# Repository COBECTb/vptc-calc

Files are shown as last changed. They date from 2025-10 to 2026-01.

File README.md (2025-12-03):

# vptc-calc
Калькулятор ВПТК (Волновой редуктор с роликами)

## Запуск

```
docker build -t vptc-calculator .
```

```
docker run --rm -it \
  -v "$(pwd)/calc-vpts.py":/app/calc-vpts.py:ro \
  -v "$(pwd)/output":/app/output \
  vptc-calculator
```

## Описание

Калькулятор генерирует 3D-модель волнового редуктора с роликами (VPTC - Variable Pace Traction Coupling) с параметрами, задаваемыми пользователем. В папку output помещается файл vptc_roller.scad который необходимо открыть в программе OpenSCAD.

## Генерируемые детали

Программа генерирует следующие основные детали:

### 1. Жёсткое колесо (Corpus редуктора) - `rigid_gear()`
- Внешний корпус редуктора с профильными впадинами
- Имеет крепёжные отверстия группы A (для крепления крышки)
- Имеет крепёжные отверстия группы B (для кожуха мотора)
- Посадочное место под подшипник 6803ZZ в корпусе
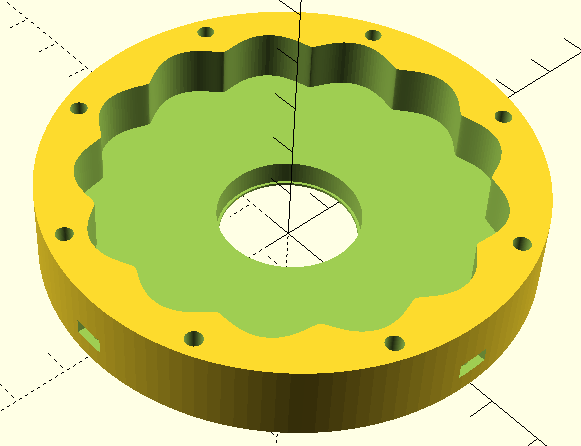
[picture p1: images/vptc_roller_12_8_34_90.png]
vptc_roller_12_8_34_90


### 2. Корпус с боковым креплением - `rigid_gear_with_bracing()`
- Усиленная версия жёсткого колеса с дополнительными элементами бокового крепления

### 3. Сепаратор - `separator()`
- Держатель роликов с фланцем под основной подшипник
- Имеет посадочное место под подшипник 688ZZ (8x16x5) на конце
- Содержит отверстия для роликов
- Имеет крепёжные отверстия для нагрузки

### 4. Ролики - `rollers()`
- Цилиндрические ролики, размещаемые в сепараторе
- Количество определяется передаточным числом

### 5. Эксцентрик - `eccentric()`
- Эксцентриковая деталь, обеспечивающая волновую передачу
- Имеет посадочное место под подшипник 6803ZZ

### 6. Вал эксцентрика - `eccentric_shaft()`
- Основной вал с эксцентриковой ступенью
- Содержит посадочные места под подшипники
- Имеет шип для крепления сепаратора

### 7. Крышка редуктора - `cap()`
- Крышка корпуса с отверстиями для крепления
- Потайные отверстия под винты М3

### 8. Крышка с боковым креплением - `cap_with_bracing()`
- Усиленная версия крышки с элементами бокового крепления

### 9. Защитный кожух мотора - `motor_cover()`
- Защитный кожух для двигателя с креплением
- Имеет отверстия для крепления двигателя
- Центральное отверстие под магнит энкодера

### 10. Соединитель редукторов - `reducer_connector()`
- Элемент для соединения нескольких редукторов

### 11. Зажим соединителей - `connector_clamp()`
- Крепежный элемент для соединителей

## Управление сборкой

Внизу, в секции "Сборка", перечисляются детали, можно их создание раскомментировать и подвигать функцией translate:

```
// === Сборка ===
rigid_gear_with_bracing();  // Корпус с боковым креплением
translate([0, 0, h_reducer+1]) cap_with_bracing();  // Крышка с боковым креплением
translate([0, 0, 0.5]) eccentric_shaft();
translate([0, 0, 14]) rotate([180,0,0]) eccentric();
translate([0, 0, ecc_shaft_h1 + ecc_spacer_h-1]) separator();
translate([0, 0, -mc_total_height-1]) motor_cover(); // кожух снизу
```

## Параметры моделирования

Параметр $fn отвечает за разрешение геометрии модели:
```
// ВПТК редуктор с роликами

$fn = 60;  // Рекомендуемое значение для 3D печати
```

В редакторе OpenSCAD есть кнопки рендеринга и экспорт в STL.

## Параметры, запрашиваемые при запуске

- **Количество точек построения профиля жесткого колеса** (по умолчанию: 600) - влияет на точность профиля
- **Передаточное число** (по умолчанию: 19) - основной параметр передачи
- **Диаметр роликов (мм)** (по умолчанию: 4.0) - диаметр роликов сепаратора
- **Высота роликов (мм)** (по умолчанию: 5.0) - высота роликов сепаратора
- **Внешний радиус впадин жесткого колеса (мм)** (по умолчанию: 29.0) - радиус профиля жесткого колеса
- **Внешний диаметр редуктора (мм)** (по умолчанию: 70.0) - общий диаметр корпуса

## Список деталей и крепежа

Программа автоматически выводит список всех необходимых деталей и крепежа, включая:
- Подшипники: 6803ZZ (17×26×5 мм), 688ZZ (8×16×5 мм), и подшипник для сепаратора (6808-2RS или 6810-2RS)
- Винты: M3×10 мм и M3×15 мм
- Гайки: M3

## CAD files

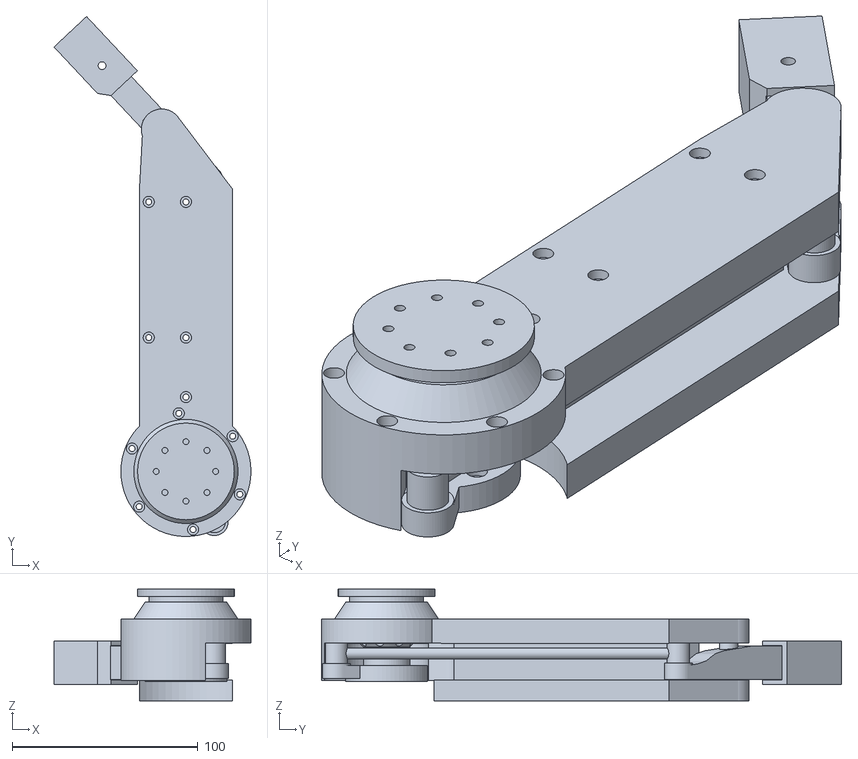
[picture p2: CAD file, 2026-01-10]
output/vptc_roller_19_4_5_70_leg_left_front.stl
106.0 x 279.8 x 60.1

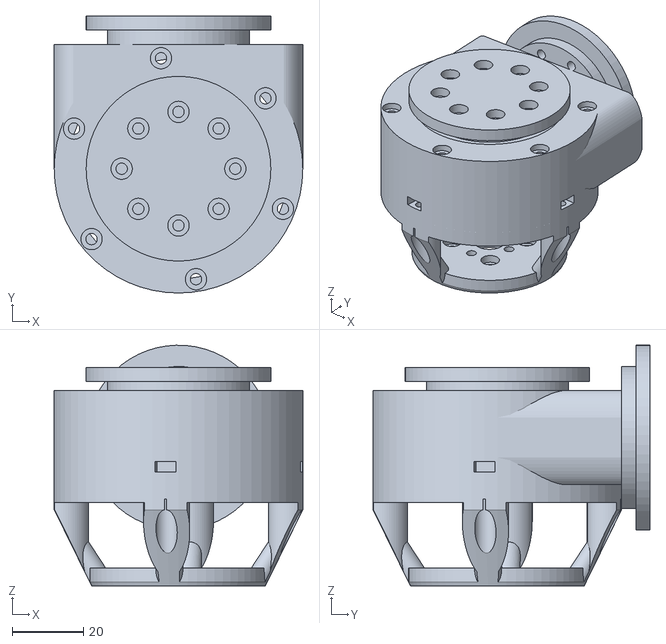
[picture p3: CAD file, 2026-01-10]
output/vptc_roller_19_4_5_70_reducer_with_bracing_and_connector.stl
70.0 x 78.0 x 67.7

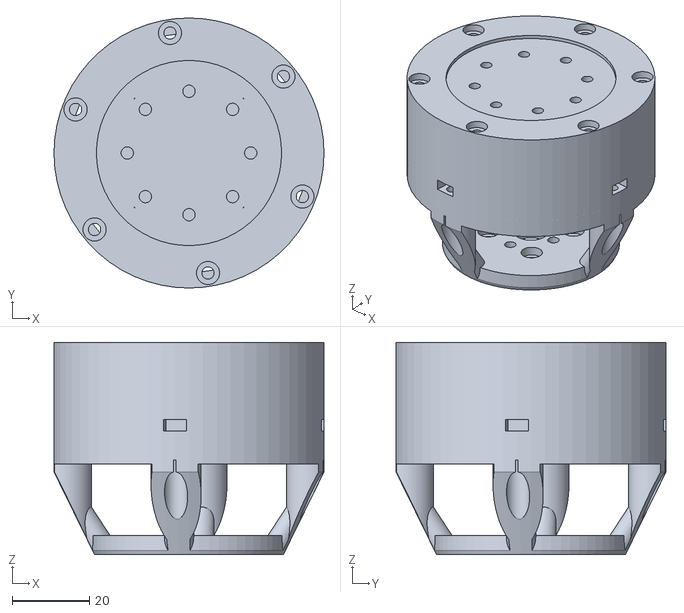
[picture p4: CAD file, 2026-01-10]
output/vptc_roller_19_4_5_70_reducer.stl
70.0 x 70.0 x 55.0

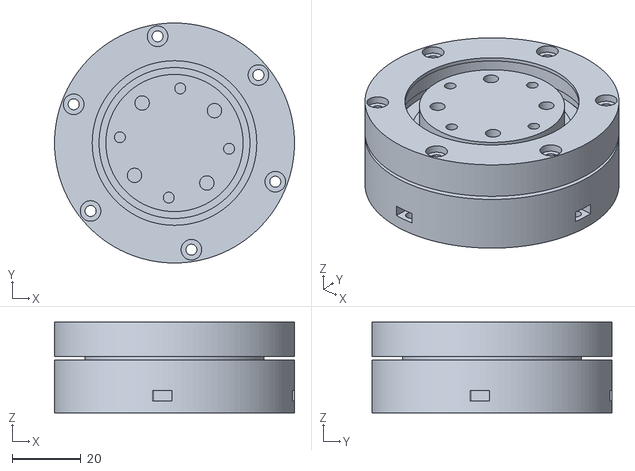
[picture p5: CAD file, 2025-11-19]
output/vptc_roller_19_4_5_70.stl
70.0 x 70.0 x 26.5

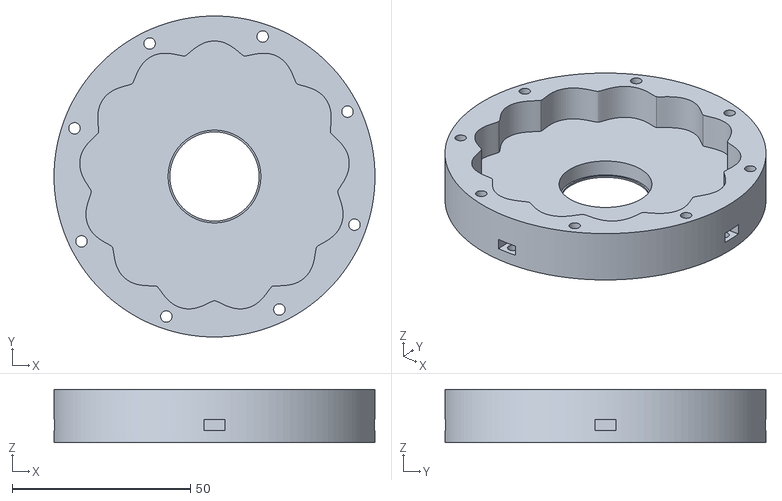
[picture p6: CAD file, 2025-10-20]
output/vptc_roller_12_8_34_90.stl
90.0 x 90.0 x 15.0

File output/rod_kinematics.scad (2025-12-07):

// ========== ФУНКЦИИ РАСЧЕТА (ваши) ==========
function calculate_rigid_linkage(
    angle1, rod_length, radius1, radius2, center1, center2
) = 
let(
    a1 = angle1,
    P1 = [center1.x + radius1 * cos(a1), center1.y + radius1 * sin(a1), center1.z],
    dx = center2.x - P1.x,
    dy = center2.y - P1.y,
    d = sqrt(dx*dx + dy*dy),
    min_length = abs(d - radius2),
    max_length = d + radius2,
    solution_exists = (rod_length >= min_length) && (rod_length <= max_length),
    P2 = solution_exists ? 
        let(
            cos_phi = (d*d + radius2*radius2 - rod_length*rod_length) / (2 * d * radius2),
            theta = atan2(P1.y - center2.y, P1.x - center2.x),
            alpha = acos(cos_phi),
            angle2 = theta + alpha,
            point2 = [center2.x + radius2 * cos(angle2), center2.y + radius2 * sin(angle2), center2.z]
        )
        point2
        : [0, 0, 0],
    angle2_result = solution_exists ? atan2(P2.y - center2.y, P2.x - center2.x) : 0
)
[
    ["point1", P1], ["point2", P2], ["angle1", angle1], ["angle2", angle2_result],
    ["solution_exists", solution_exists], ["distance", rod_length],
    ["min_possible", min_length], ["max_possible", max_length]
];

function get_value(data, key) = 
    let(idx = search([key], data, num_returns_per_match=1)[0])
    data[idx][1];

// ========== МОДУЛИ ДЛЯ ОТРИСОВКИ ==========

// Модуль для соединения двух точек цилиндром
module connect_points(p1, p2, diameter = 3) {
    hole_diameter= 3;
    plate_thickness = 2;       // Толщина пластины
    plate_diameter = hole_diameter * 3; // Диаметр круглой пластины

    vec = p2 - p1;
    length = norm(vec);
    
    // Угол в плоскости XY
    angle = atan2(vec.y, vec.x);
    
    translate(p1)
    rotate([0, 90, angle])  // Вот это правильный порядок!
        cylinder(h = length, d = diameter, center = false);
    translate(p1)
    difference() {
                cylinder( h = plate_thickness, d = plate_diameter, center = true );
                // Отверстие для оси шарнира (перпендикулярно тяге)
                cylinder( h = plate_thickness * 2, d = hole_diameter, center = true );
            };
    translate(p2)
    difference() {
                cylinder( h = plate_thickness+10, d = plate_diameter, center = true );
                // Отверстие для оси шарнира (перпендикулярно тяге)
                cylinder( h = plate_thickness * 2, d = hole_diameter, center = true );
            };
}

// Модуль для отрисовки качалки (рычага)
module draw_arm(center, radius, angle, width = 6, thickness = 4, color = "red") {
    color(color) {
        // Центральная ступица
        translate(center)
            cylinder(h = thickness + 2, d = 10, center = true);
        
        // Рычаг
        translate(center)
        rotate([0, 0, angle]) {
            // Основание рычага
            cylinder(h = thickness, d = width, center = true);
            
            // Длина рычага до точки крепления
            translate([radius, 0, 0])
                cylinder(h = thickness, d = width, center = true);
            
            // Соединяющая часть
            hull() {
                cylinder(h = thickness, d = width, center = true);
                translate([radius, 0, 0])
                    cylinder(h = thickness, d = width, center = true);
            }
            
            // Точка крепления (усиленная)
            translate([radius, 0, 0])
                cylinder(h = thickness + 4, d = 8, center = true);
        }
    }
}

// Модуль для отрисовки основания
module draw_base(position, size = [40, 40, 5], color = "gray") {
    color(color, 0.5)
    translate(position - [0, 0, size.z/2])
        cube(size, center = true);
}

// Модуль для отрисовки всей системы
module draw_linkage_system(
    servo_angle, rod_length, radius1, radius2, center1, center2,
    show_trajectory = true
) {
    // Выполняем расчет
    result = calculate_rigid_linkage(
        servo_angle, rod_length, radius1, radius2, center1, center2
    );
    
    // Извлекаем результаты
    point1 = get_value(result, "point1");
    point2 = get_value(result, "point2");
    angle2 = get_value(result, "angle2");
    solution_exists = get_value(result, "solution_exists");
    
    // Если решение существует - рисуем механизм
    if (solution_exists) {
        // 1. ОСНОВАНИЯ
        draw_base(center1, [50, 50, 8], "lightgray");
        draw_base(center2, [50, 50, 8], "lightgray");
        
        // 2. ПЕРВАЯ КАЧАЛКА (сервопривод)
        draw_arm(center1, radius1, servo_angle, 6, 4, "red");
        
        // 3. ВТОРАЯ КАЧАЛКА (колено)
        draw_arm(center2, radius2, angle2, 6, 4, "blue");
        
        // 4. ТЯГА (стержень)
        color("silver") {
            connect_points(point1, point2, 5);
            
            // Шарнирные шарики на концах
            translate(point1) sphere(d = 10);
            translate(point2) sphere(d = 10);
        }
        
        // 5. ЦЕНТРЫ ВРАЩЕНИЯ (оси)
        color("black") {
            // Ось сервопривода
            translate(center1)
                cylinder(h = 15, d = 4, center = true);
            
            // Ось колена
            translate(center2)
                cylinder(h = 15, d = 4, center = true);
        }
        
        // 6. ТРАЕКТОРИИ ДВИЖЕНИЯ (полупрозрачные)
        if (show_trajectory) {
            // Траектория точки P1
            color("red", 0.2)
            translate(center1)
                cylinder(h = 0.5, r = radius1, center = true);
            
            // Траектория точки P2 для всех углов
            color("blue", 0.2) 
            for(ang = [0:10:360]) {
                test_result = calculate_rigid_linkage(
                    ang, rod_length, radius1, radius2, center1, center2
                );
                if (get_value(test_result, "solution_exists")) {
                    test_p2 = get_value(test_result, "point2");
                    translate(test_p2)
                        sphere(r = 1);
                }
            }
        }
        
        // 7. ИНФОРМАЦИОННАЯ ПАНЕЛЬ
        color("black")
        translate([0, -50, 20])
        linear_extrude(1) {
            text(str("Сервопривод: ", round(servo_angle), "°"), 
                 size = 5, halign = "center");
            
            translate([0, -7, 0])
            text(str("Колено: ", round(angle2), "°"), 
                 size = 5, halign = "center");
            
            translate([0, -14, 0])
            text(str("Длина тяги: ", rod_length, "мм"), 
                 size = 5, halign = "center");
        }
        
    } else {
        // Если решения нет - показываем сообщение об ошибке
        color("red")
        translate([0, 0, 30])
        linear_extrude(2)
            text("НЕТ РЕШЕНИЯ!", size = 10, halign = "center");
    }
}

// ========== ПАРАМЕТРЫ И ВЫЗОВ ==========

// Параметры механизма
rod_length = 90;
radius1 = 20;
radius2 = 25;
center1 = [0, 0, 0];
center2 = [80, 30, 0];

// Для анимации используем $t (от 0 до 1)
servo_angle = $t * 270 - 135;  // От -135° до +135°

// Отрисовываем систему
draw_linkage_system(
    servo_angle = servo_angle,
    rod_length = rod_length,
    radius1 = radius1,
    radius2 = radius2,
    center1 = center1,
    center2 = center2,
    show_trajectory = true
);

// ========== ДОПОЛНИТЕЛЬНАЯ ВИЗУАЛИЗАЦИЯ ==========

// Ради удобства - рисуем сетку координат
%color("gray", 0.2) {
    // Оси координат
    cylinder(h = 100, r = 0.5, center = true); // Z
    rotate([90, 0, 0]) cylinder(h = 100, r = 0.5, center = true); // Y
    rotate([0, 90, 0]) cylinder(h = 100, r = 0.5, center = true); // X
    
    // Подписи осей
    translate([105, 0, 0]) text("X", size = 5);
    translate([0, 105, 0]) text("Y", size = 5);
    translate([0, 0, 105]) text("Z", size = 5);
}

// ========== ПРОВЕРОЧНЫЙ РАСЧЕТ ==========

// Выводим значения в консоль для текущего угла
echo(" ");
echo("=== РАСЧЕТ ДЛЯ УГЛА ", servo_angle, "° ===");

result = calculate_rigid_linkage(
    servo_angle, rod_length, radius1, radius2, center1, center2
);

point1 = get_value(result, "point1");
point2 = get_value(result, "point2");
angle2 = get_value(result, "angle2");
solution_exists = get_value(result, "solution_exists");
min_possible = get_value(result, "min_possible");
max_possible = get_value(result, "max_possible");

echo("Точка 1: ", point1);
echo("Точка 2: ", point2);
echo("Угол колена: ", angle2, "° (", angle2 * 180 / 3.14159, "°)");
echo("Длина тяги (расчетная): ", norm(point2 - point1), "мм");
echo("Диапазон возможных длин: от ", min_possible, " до ", max_possible, "мм");
echo("Решение существует: ", solution_exists);

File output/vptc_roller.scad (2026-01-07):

// ВПТК редуктор с роликами (для 3D-печати)
$fn = 60;
// Параметры
d_roller = 4.000;
h_roller = 5.000;
separator_h = 9.000;
eccentric_h = 7.000;
Rsep_m = 25.200;
Rsep_out = 26.080;
Rsep_in = 24.320;
D_out = 70.000;
h_reducer = 15.500;
bearing_inner = 40.0;
// Высота профильного выреза
h_cut = h_roller + 5;
cap_thickness = 11.0;
eccentricity = 0.800;
// --- Параметры вала эксцентрика ---
ecc_shaft_h1 = 5.000;   // основание под 6803ZZ
ecc_spacer_h = 2.500;   // проставка
ecc_shaft_h2 = 6.000;   // эксцентриковая ступень
ecc_pin_h = 6.000;      // шип под 688ZZ
// --- Параметры кожуха мотора ---
mc_motor_plate_d = 50.0;
mc_base_thickness = 4.0;
mc_encoder_hole_d = 10.0;
mc_motor_hole_1 = 16.0;
mc_motor_hole_2 = 19.0;
mc_nut_pad_radius = 24.0;
mc_nut_pad_d = 6.0;
mc_nut_pad_h = 3.0;
mc_total_height = 27.5;
mc_ring_width = 4.0;
mc_ring_height = 5.0;
mc_countersink_d = 6.0;
mc_countersink_h = 2.0;
// --- Параметры бокового крепления ---
bracing_offset_y = 29.0;  // смещение по Y
bracing_offset_z = 17.5;  // смещение по Z
bracing_offset_x = 2.2;  // смещение по X

// === Группа B: отверстия под кожух мотора нужны в двух функциях===
motor_angles = [174.0, 264.0, 354.0, 84.0];
motor_radius = 32.000;

// Расстояния между отверстиями в боковом креплении
side_short = 12.246;
side_long = 29.564;

zazor=0; //отступ для раздельной печати деталей, чтобы при импорте stl можно было разделить на отделтные детали
// === Вспомогательные модули для бокового крепления ===
module oval_cone(height, bottom_width, bottom_depth, top_width, top_depth, center = false) {
    hull() {
        // Нижнее основание
        translate([0, 0, center ? -height/2 : 0])
        scale([bottom_width/2, bottom_depth/2, 1])
        cylinder(h = 0.1, r = 1, center = true, $fn = 64);
        
        // Верхнее основание
        translate([0, 0, center ? height/2 : height])
        scale([top_width/2, top_depth/2, 1])
        cylinder(h = 0.1, r = 1, center = true, $fn = 64);
    }
}

module oval_cone_diff_half(height, bottom_width, bottom_depth, top_width, top_depth, center = false) {
    difference() { 
        cube([height, height, height], center = center);
        // Вычитаем овальный конус
        oval_cone(height, bottom_width, bottom_depth, top_width, top_depth, center = center);
        translate([0, height/4, 0]) cube([height, height/2, height], center = center);
    }
}

// === Корпус (жёсткое колесо) ===
module rigid_gear() {
    difference() {
        cylinder(h = h_reducer, r = D_out / 2, center = false);
        translate([0, 0, h_reducer - h_cut])
            linear_extrude(height = h_cut, center = false)
                polygon(points = [
                [0.00000, 28.00000], [0.55458, 27.96049], [1.08358, 27.84861], [1.56964, 27.68091], [2.00602, 27.47706],
        [2.39362, 27.25494], [2.73674, 27.02909], [3.03997, 26.81126], [3.30657, 26.61130], [3.53787, 26.43755],
        [3.73313, 26.29670], [3.88995, 26.19284], [4.00545, 26.12612], [4.07887, 26.09136], [4.11549, 26.07829],
        [4.12987, 26.07497], [4.14457, 26.07368], [4.18344, 26.07480], [4.26401, 26.08517], [4.39447, 26.11293],
        [4.57571, 26.16324], [4.80494, 26.23687], [5.07860, 26.33064], [5.39395, 26.43843], [5.74965, 26.55189],
        [6.14577, 26.66065], [6.58304, 26.75213], [7.06105, 26.81115], [7.57515, 26.82045], [8.11283, 26.76338],
        [8.65248, 26.62958], [9.16770, 26.42064], [9.63624, 26.15076], [10.04669, 25.84106], [10.39872, 25.51235],
        [10.69871, 25.18132], [10.95525, 24.86049], [11.17632, 24.55962], [11.36808, 24.28706], [11.53437, 24.05034],
        [11.67654, 23.85604], [11.79359, 23.70881], [11.88282, 23.60967], [11.94190, 23.55392], [11.97270, 23.53017],
        [11.98535, 23.52257], [11.99893, 23.51680], [12.03624, 23.50585], [12.11608, 23.49082], [12.24873, 23.47691],
        [12.43665, 23.46875], [12.67741, 23.46794], [12.96665, 23.47255], [13.29987, 23.47762], [13.67322, 23.47561],
        [14.08357, 23.45664], [14.52771, 23.40852], [15.00056, 23.31694], [15.49237, 23.16691], [15.98610, 22.94649],
        [16.45799, 22.65248], [16.88343, 22.29454], [17.24564, 21.89309], [17.54030, 21.47171], [17.77352, 21.05030],
        [17.95653, 20.64277], [18.10137, 20.25837], [18.21865, 19.90391], [18.31680, 19.58544], [18.40180, 19.30892],
        [18.47697, 19.08020], [18.54280, 18.90400], [18.59702, 18.78213], [18.63599, 18.71086], [18.65794, 18.67875],
        [18.66762, 18.66762], [18.67875, 18.65794], [18.71086, 18.63599], [18.78213, 18.59702], [18.90400, 18.54280],
        [19.08020, 18.47697], [19.30892, 18.40180], [19.58544, 18.31680], [19.90391, 18.21865], [20.25837, 18.10137],
        [20.64277, 17.95653], [21.05030, 17.77352], [21.47171, 17.54030], [21.89309, 17.24564], [22.29454, 16.88343],
        [22.65248, 16.45799], [22.94649, 15.98610], [23.16691, 15.49237], [23.31694, 15.00056], [23.40852, 14.52771],
        [23.45664, 14.08357], [23.47561, 13.67322], [23.47762, 13.29987], [23.47255, 12.96665], [23.46794, 12.67741],
        [23.46875, 12.43665], [23.47691, 12.24873], [23.49082, 12.11608], [23.50585, 12.03624], [23.51680, 11.99893],
        [23.52257, 11.98535], [23.53017, 11.97270], [23.55392, 11.94190], [23.60967, 11.88282], [23.70881, 11.79359],
        [23.85604, 11.67654], [24.05034, 11.53437], [24.28706, 11.36808], [24.55962, 11.17632], [24.86049, 10.95525],
        [25.18132, 10.69871], [25.51235, 10.39872], [25.84106, 10.04669], [26.15076, 9.63624], [26.42064, 9.16770],
        [26.62958, 8.65248], [26.76338, 8.11283], [26.82045, 7.57515], [26.81115, 7.06105], [26.75213, 6.58304],
        [26.66065, 6.14577], [26.55189, 5.74965], [26.43843, 5.39395], [26.33064, 5.07860], [26.23687, 4.80494],
        [26.16324, 4.57571], [26.11293, 4.39447], [26.08517, 4.26401], [26.07480, 4.18344], [26.07368, 4.14457],
        [26.07497, 4.12987], [26.07829, 4.11549], [26.09136, 4.07887], [26.12612, 4.00545], [26.19284, 3.88995],
        [26.29670, 3.73313], [26.43755, 3.53787], [26.61130, 3.30657], [26.81126, 3.03997], [27.02909, 2.73674],
        [27.25494, 2.39362], [27.47706, 2.00602], [27.68091, 1.56964], [27.84861, 1.08358], [27.96049, 0.55458],
        [28.00000, 0.00000], [27.96049, -0.55458], [27.84861, -1.08358], [27.68091, -1.56964], [27.47706, -2.00602],
        [27.25494, -2.39362], [27.02909, -2.73674], [26.81126, -3.03997], [26.61130, -3.30657], [26.43755, -3.53787],
        [26.29670, -3.73313], [26.19284, -3.88995], [26.12612, -4.00545], [26.09136, -4.07887], [26.07829, -4.11549],
        [26.07497, -4.12987], [26.07368, -4.14457], [26.07480, -4.18344], [26.08517, -4.26401], [26.11293, -4.39447],
        [26.16324, -4.57571], [26.23687, -4.80494], [26.33064, -5.07860], [26.43843, -5.39395], [26.55189, -5.74965],
        [26.66065, -6.14577], [26.75213, -6.58304], [26.81115, -7.06105], [26.82045, -7.57515], [26.76338, -8.11283],
        [26.62958, -8.65248], [26.42064, -9.16770], [26.15076, -9.63624], [25.84106, -10.04669], [25.51235, -10.39872],
        [25.18132, -10.69871], [24.86049, -10.95525], [24.55962, -11.17632], [24.28706, -11.36808], [24.05034, -11.53437],
        [23.85604, -11.67654], [23.70881, -11.79359], [23.60967, -11.88282], [23.55392, -11.94190], [23.53017, -11.97270],
        [23.52257, -11.98535], [23.51680, -11.99893], [23.50585, -12.03624], [23.49082, -12.11608], [23.47691, -12.24873],
        [23.46875, -12.43665], [23.46794, -12.67741], [23.47255, -12.96665], [23.47762, -13.29987], [23.47561, -13.67322],
        [23.45664, -14.08357], [23.40852, -14.52771], [23.31694, -15.00056], [23.16691, -15.49237], [22.94649, -15.98610],
        [22.65248, -16.45799], [22.29454, -16.88343], [21.89309, -17.24564], [21.47171, -17.54030], [21.05030, -17.77352],
        [20.64277, -17.95653], [20.25837, -18.10137], [19.90391, -18.21865], [19.58544, -18.31680], [19.30892, -18.40180],
        [19.08020, -18.47697], [18.90400, -18.54280], [18.78213, -18.59702], [18.71086, -18.63599], [18.67875, -18.65794],
        [18.66762, -18.66762], [18.65794, -18.67875], [18.63599, -18.71086], [18.59702, -18.78213], [18.54280, -18.90400],
        [18.47697, -19.08020], [18.40180, -19.30892], [18.31680, -19.58544], [18.21865, -19.90391], [18.10137, -20.25837],
        [17.95653, -20.64277], [17.77352, -21.05030], [17.54030, -21.47171], [17.24564, -21.89309], [16.88343, -22.29454],
        [16.45799, -22.65248], [15.98610, -22.94649], [15.49237, -23.16691], [15.00056, -23.31694], [14.52771, -23.40852],
        [14.08357, -23.45664], [13.67322, -23.47561], [13.29987, -23.47762], [12.96665, -23.47255], [12.67741, -23.46794],
        [12.43665, -23.46875], [12.24873, -23.47691], [12.11608, -23.49082], [12.03624, -23.50585], [11.99893, -23.51680],
        [11.98535, -23.52257], [11.97270, -23.53017], [11.94190, -23.55392], [11.88282, -23.60967], [11.79359, -23.70881],
        [11.67654, -23.85604], [11.53437, -24.05034], [11.36808, -24.28706], [11.17632, -24.55962], [10.95525, -24.86049],
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

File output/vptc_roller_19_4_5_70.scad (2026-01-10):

// ВПТК редуктор с роликами (для 3D-печати)
$fn = 60;
// Параметры
d_roller = 4.000;
h_roller = 5.000;
separator_h = 9.000;
eccentric_h = 7.000;
Rsep_m = 25.200;
Rsep_out = 26.080;
Rsep_in = 24.320;
D_out = 70.000;
h_reducer = 15.500;
bearing_inner = 40.0;
// Высота профильного выреза
h_cut = h_roller + 5;
cap_thickness = 11.0;
eccentricity = 0.800;
// --- Параметры вала эксцентрика ---
ecc_shaft_h1 = 5.000;   // основание под 6803ZZ
ecc_spacer_h = 2.500;   // проставка
ecc_shaft_h2 = 6.000;   // эксцентриковая ступень
ecc_pin_h = 6.000;      // шип под 688ZZ
// --- Параметры кожуха мотора ---
mc_motor_plate_d = 50.0;
mc_base_thickness = 4.0;
mc_encoder_hole_d = 10.0;
mc_motor_hole_1 = 16.0;
mc_motor_hole_2 = 19.0;
mc_nut_pad_radius = 24.0;
mc_nut_pad_d = 6.0;
mc_nut_pad_h = 3.0;
mc_total_height = 27.5;
mc_ring_width = 4.0;
mc_ring_height = 5.0;
mc_countersink_d = 6.0;
mc_countersink_h = 2.0;
// --- Параметры бокового крепления ---
bracing_offset_y = 29.0;  // смещение по Y
bracing_offset_z = 17.5;  // смещение по Z
bracing_offset_x = 2.2;  // смещение по X

// === Группа B: отверстия под кожух мотора нужны в двух функциях===
motor_angles = [174.0, 264.0, 354.0, 84.0];
motor_radius = 32.000;

// Расстояния между отверстиями в боковом креплении
side_short = 12.246;
side_long = 29.564;

zazor=0; //отступ для раздельной печати деталей, чтобы при импорте stl можно было разделить на отделтные детали
// === Вспомогательные модули для бокового крепления ===
module oval_cone(height, bottom_width, bottom_depth, top_width, top_depth, center = false) {
    hull() {
        // Нижнее основание
        translate([0, 0, center ? -height/2 : 0])
        scale([bottom_width/2, bottom_depth/2, 1])
        cylinder(h = 0.1, r = 1, center = true, $fn = 64);
        
        // Верхнее основание
        translate([0, 0, center ? height/2 : height])
        scale([top_width/2, top_depth/2, 1])
        cylinder(h = 0.1, r = 1, center = true, $fn = 64);
    }
}

module oval_cone_diff_half(height, bottom_width, bottom_depth, top_width, top_depth, center = false) {
    difference() { 
        cube([height, height, height], center = center);
        // Вычитаем овальный конус
        oval_cone(height, bottom_width, bottom_depth, top_width, top_depth, center = center);
        translate([0, height/4, 0]) cube([height, height/2, height], center = center);
    }
}

// === Корпус (жёсткое колесо) ===
module rigid_gear() {
    difference() {
        cylinder(h = h_reducer, r = D_out / 2, center = false);
        translate([0, 0, h_reducer - h_cut])
            linear_extrude(height = h_cut, center = false)
                polygon(points = [
                [0.00000, 28.00000], [0.55458, 27.96049], [1.08358, 27.84861], [1.56964, 27.68091], [2.00602, 27.47706],
        [2.39362, 27.25494], [2.73674, 27.02909], [3.03997, 26.81126], [3.30657, 26.61130], [3.53787, 26.43755],
        [3.73313, 26.29670], [3.88995, 26.19284], [4.00545, 26.12612], [4.07887, 26.09136], [4.11549, 26.07829],
        [4.12987, 26.07497], [4.14457, 26.07368], [4.18344, 26.07480], [4.26401, 26.08517], [4.39447, 26.11293],
        [4.57571, 26.16324], [4.80494, 26.23687], [5.07860, 26.33064], [5.39395, 26.43843], [5.74965, 26.55189],
        [6.14577, 26.66065], [6.58304, 26.75213], [7.06105, 26.81115], [7.57515, 26.82045], [8.11283, 26.76338],
        [8.65248, 26.62958], [9.16770, 26.42064], [9.63624, 26.15076], [10.04669, 25.84106], [10.39872, 25.51235],
        [10.69871, 25.18132], [10.95525, 24.86049], [11.17632, 24.55962], [11.36808, 24.28706], [11.53437, 24.05034],
        [11.67654, 23.85604], [11.79359, 23.70881], [11.88282, 23.60967], [11.94190, 23.55392], [11.97270, 23.53017],
        [11.98535, 23.52257], [11.99893, 23.51680], [12.03624, 23.50585], [12.11608, 23.49082], [12.24873, 23.47691],
        [12.43665, 23.46875], [12.67741, 23.46794], [12.96665, 23.47255], [13.29987, 23.47762], [13.67322, 23.47561],
        [14.08357, 23.45664], [14.52771, 23.40852], [15.00056, 23.31694], [15.49237, 23.16691], [15.98610, 22.94649],
        [16.45799, 22.65248], [16.88343, 22.29454], [17.24564, 21.89309], [17.54030, 21.47171], [17.77352, 21.05030],
        [17.95653, 20.64277], [18.10137, 20.25837], [18.21865, 19.90391], [18.31680, 19.58544], [18.40180, 19.30892],
        [18.47697, 19.08020], [18.54280, 18.90400], [18.59702, 18.78213], [18.63599, 18.71086], [18.65794, 18.67875],
        [18.66762, 18.66762], [18.67875, 18.65794], [18.71086, 18.63599], [18.78213, 18.59702], [18.90400, 18.54280],
        [19.08020, 18.47697], [19.30892, 18.40180], [19.58544, 18.31680], [19.90391, 18.21865], [20.25837, 18.10137],
        [20.64277, 17.95653], [21.05030, 17.77352], [21.47171, 17.54030], [21.89309, 17.24564], [22.29454, 16.88343],
        [22.65248, 16.45799], [22.94649, 15.98610], [23.16691, 15.49237], [23.31694, 15.00056], [23.40852, 14.52771],
        [23.45664, 14.08357], [23.47561, 13.67322], [23.47762, 13.29987], [23.47255, 12.96665], [23.46794, 12.67741],
        [23.46875, 12.43665], [23.47691, 12.24873], [23.49082, 12.11608], [23.50585, 12.03624], [23.51680, 11.99893],
        [23.52257, 11.98535], [23.53017, 11.97270], [23.55392, 11.94190], [23.60967, 11.88282], [23.70881, 11.79359],
        [23.85604, 11.67654], [24.05034, 11.53437], [24.28706, 11.36808], [24.55962, 11.17632], [24.86049, 10.95525],
        [25.18132, 10.69871], [25.51235, 10.39872], [25.84106, 10.04669], [26.15076, 9.63624], [26.42064, 9.16770],
        [26.62958, 8.65248], [26.76338, 8.11283], [26.82045, 7.57515], [26.81115, 7.06105], [26.75213, 6.58304],
        [26.66065, 6.14577], [26.55189, 5.74965], [26.43843, 5.39395], [26.33064, 5.07860], [26.23687, 4.80494],
        [26.16324, 4.57571], [26.11293, 4.39447], [26.08517, 4.26401], [26.07480, 4.18344], [26.07368, 4.14457],
        [26.07497, 4.12987], [26.07829, 4.11549], [26.09136, 4.07887], [26.12612, 4.00545], [26.19284, 3.88995],
        [26.29670, 3.73313], [26.43755, 3.53787], [26.61130, 3.30657], [26.81126, 3.03997], [27.02909, 2.73674],
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

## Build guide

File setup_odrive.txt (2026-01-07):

odrv0.axis0.error=0
odrv0.axis0.requested_state = AXIS_STATE_FULL_CALIBRATION_SEQUENCE
while odrv0.axis0.current_state != AXIS_STATE_IDLE:
        time.sleep(0.1)

odrv0.axis1.error=0
odrv0.axis1.requested_state = AXIS_STATE_FULL_CALIBRATION_SEQUENCE
while odrv0.axis1.current_state != AXIS_STATE_IDLE:
        time.sleep(0.1)
odrv0.axis1.requested_state = AXIS_STATE_CLOSED_LOOP_CONTROL

odrv0.erase_configuration()
odrv0.reboot()

# ─── 1. ПИТАНИЕ (с запасом на просадки) ────────────
odrv0.config.dc_bus_undervoltage_trip_level = 13.5   
odrv0.config.dc_bus_overvoltage_trip_level = 18.0    
odrv0.config.brake_resistance = 2.0                   

# ─── 2. ОСЬ 0 ───────────────────────────────────────
ax = odrv0.axis0

# Мотор
ax.motor.config.pole_pairs = 7                        
ax.motor.config.calibration_current = 5.0             
ax.motor.config.current_lim = 35.0                    
ax.motor.config.resistance_calib_max_voltage = 2.5    

# Энкодер
ax.encoder.config.mode = ENCODER_MODE_INCREMENTAL      
ax.encoder.config.cpr = 4096                          
ax.encoder.config.use_index = True
ax.encoder.config.zero_count_on_find_idx = True 
ax.encoder.config.idx_search_unidirectional = False                  

# Динамика (плавно, но уверенно)
ax.controller.config.control_mode = CONTROL_MODE_POSITION_CONTROL 
ax.controller.config.input_mode = INPUT_MODE_TRAP_TRAJ            

ax.trap_traj.config.vel_limit = 4.0      
ax.trap_traj.config.accel_limit = 8.0    
ax.trap_traj.config.decel_limit = 8.0    
ax.controller.config.vel_limit = 6.0     
ax.controller.config.pos_gain = 25.0     

# CAN
ax.config.can_node_id = 2  

# ─── 3. ОСЬ 1 (аналогично) ──────────────────────────
ax = odrv0.axis1

# Мотор
ax.motor.config.pole_pairs = 7
ax.motor.config.calibration_current = 5.0
ax.motor.config.current_lim = 35.0
ax.motor.config.resistance_calib_max_voltage = 2.5

# Энкодер
ax.encoder.config.mode = ENCODER_MODE_INCREMENTAL      
ax.encoder.config.cpr = 4096
ax.encoder.config.use_index = True
ax.encoder.config.zero_count_on_find_idx = True 
ax.encoder.config.idx_search_unidirectional = False 

# Управление
ax.controller.config.control_mode = CONTROL_MODE_POSITION_CONTROL  
ax.controller.config.input_mode = INPUT_MODE_TRAP_TRAJ           

ax.trap_traj.config.vel_limit = 4.0
ax.trap_traj.config.accel_limit = 8.0
ax.trap_traj.config.decel_limit = 8.0
ax.controller.config.vel_limit = 6.0
ax.controller.config.pos_gain = 25.0

ax.config.can_node_id = 3

# ─── 4. Сохранить и перезагрузить ───────────────────
odrv0.save_configuration()
odrv0.reboot()

import time

# === КАЛИБРОВКА 2 ОСЕЙ В ODRIVE-TOOL (MT6816, с индексом Z) ===
# Все состояния — только из вашего списка enum

def wait_for_idle(ax, label=""):
    print(f"   → {label}...", end="", flush=True)
    while ax.current_state != AXIS_STATE_IDLE:
        time.sleep(0.2)
        print(".", end="", flush=True)
    print(" ✅")

print("🧹 Сброс ошибок...")
odrv0.axis0.error = 0
odrv0.axis0.motor.error = 0
odrv0.axis0.encoder.error = 0
odrv0.axis1.error = 0
odrv0.axis1.motor.error = 0
odrv0.axis1.encoder.error = 0

print("\n⚙️  Настройка энкодеров (MT6816)...")
for ax in [odrv0.axis0, odrv0.axis1]:
    ax.encoder.config.mode = ENCODER_MODE_INCREMENTAL
    ax.encoder.config.cpr = 4096
    ax.encoder.config.use_index = True
    ax.encoder.config.zero_count_on_find_idx = True
    ax.encoder.config.idx_search_unidirectional = False
    ax.config.calibration_lockin.vel = 1.0
    ax.config.calibration_lockin.accel = 3.0

print("\n" + "="*50)
print("🛠 ОСЬ 0")
print("="*50)
ax = odrv0.axis0
ax.requested_state = AXIS_STATE_MOTOR_CALIBRATION
wait_for_idle(ax, "мотор")
ax.requested_state = AXIS_STATE_ENCODER_DIR_FIND
wait_for_idle(ax, "направление")
print("🔍 Поиск Z...")
ax.requested_state = AXIS_STATE_ENCODER_INDEX_SEARCH
wait_for_idle(ax, "индекс")
ax.requested_state = AXIS_STATE_ENCODER_OFFSET_CALIBRATION
wait_for_idle(ax, "offset")

print("\n" + "="*50)
print("🛠 ОСЬ 1")
print("="*50)
ax = odrv0.axis1
ax.requested_state = AXIS_STATE_MOTOR_CALIBRATION
wait_for_idle(ax, "мотор")
ax.requested_state = AXIS_STATE_ENCODER_DIR_FIND
wait_for_idle(ax, "направление")
print("🔍 Поиск Z...")
ax.requested_state = AXIS_STATE_ENCODER_INDEX_SEARCH
wait_for_idle(ax, "индекс")
ax.requested_state = AXIS_STATE_ENCODER_OFFSET_CALIBRATION
wait_for_idle(ax, "offset")

print("\n🔖 Подтверждение...")
odrv0.axis0.motor.config.pre_calibrated = True
odrv0.axis0.encoder.config.pre_calibrated = True
odrv0.axis1.motor.config.pre_calibrated = True
odrv0.axis1.encoder.config.pre_calibrated = True

print("🚀 Автозапуск...")
odrv0.axis0.config.startup_closed_loop_control = True
odrv0.axis1.config.startup_closed_loop_control = True

print("💾 Сохранение...")
odrv0.save_configuration()
print("🔄 Перезагрузка...")
odrv0.reboot()

odrv0.axis0.config.startup_motor_calibration = True
odrv0.axis0.config.startup_encoder_index_search = True
odrv0.axis0.config.startup_encoder_offset_calibration = True
odrv0.axis0.config.startup_closed_loop_control = True

# Для оси 1:
odrv0.axis1.config.startup_motor_calibration = True
odrv0.axis1.config.startup_encoder_index_search = True
odrv0.axis1.config.startup_encoder_offset_calibration = True
odrv0.axis1.config.startup_closed_loop_control = True

# Сохранить
odrv0.save_configuration()
odrv0.reboot()

odrv0.axis0.controller.input_pos=-3
odrv1.axis0.controller.input_pos=4

odrv0.axis0.controller.input_pos=3
odrv1.axis0.controller.input_pos=-2

odrv0.axis0.controller.input_pos=3
odrv0.axis1.controller.input_pos=3

odrv0.axis0.controller.input_pos=-3
odrv0.axis1.controller.input_pos=-3

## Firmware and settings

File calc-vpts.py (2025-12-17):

import numpy as np
import sys
import os
import math

def prompt_value(prompt, default, value_type=float):
    user_input = input(f"{prompt} (по умолчанию: {default}): ")
    if user_input.strip() == "":
        return default
    try:
        return value_type(user_input)
    except ValueError:
        print("Ошибка: некорректное значение. Используем значение по умолчанию.")
        return default

# === Ввод параметров ===
RESOLUTION = prompt_value("Количество точек построения профиля жесткого колеса", 600, int)
i = prompt_value("Передаточное число", 19, int)
d_roller = prompt_value("Диаметр роликов (мм)", 4.0)
h_roller = prompt_value("Высота роликов (мм)", 5.0)
Rout = prompt_value("Внешний радиус впадин жесткого колеса (мм)", 28.0)
D = prompt_value("Внешний диаметр редуктора (мм)", 70.0)
u = 1

# === Расчёты ===
e = 0.2 * d_roller
zg = (i + 1) * u
z_rollers = i
Rin = Rout - 2 * e
r_roller = d_roller / 2
rd = Rin + e - d_roller
hc = 2.2 * e  # толщина сепаратора (для радиусов)

# Радиусы сепаратора
Rsep_m = rd + r_roller
Rsep_out = Rsep_m + hc / 2
Rsep_in = Rsep_m - hc / 2

# Высоты деталей
separator_h = h_roller + 4          # высота сепаратора
eccentric_h = h_roller + 2          # высота эксцентрика

# === Параметры вала эксцентрика ===
ecc_shaft_h1 = 5.0    # основание под 6803ZZ в корпусе (ширина подшипника)
ecc_spacer_h = 2.5    # проставка
ecc_shaft_h2 = 6.0    # эксцентриковая ступень под 6803ZZ в ECC
ecc_pin_h = 6.0       # шип под 688ZZ в сепараторе
eccentricity = e

# === Параметры защитного кожуха мотора ===
mc_motor_plate_d = 50.0   # диаметр площадки под двигатель
mc_base_thickness = 4.0   # толщина нижней плиты
mc_encoder_hole_d = 10.0  # центральное отверстие под магнит
mc_motor_hole_1 = 16.0    # расстояние между первой парой отверстий
mc_motor_hole_2 = 19.0    # расстояние между второй парой отверстий
mc_nut_pad_radius = 24.0  # радиус закладных площадок
mc_nut_pad_d = 6.0        # диаметр площадки под гайку
mc_nut_pad_h = 3.0        # высота выступа площадки
mc_ring_width = 4.0       # ширина кольца
mc_ring_height = 5.0      # высота кольца
mc_countersink_d = 6.0    # диаметр потайного отверстия
mc_countersink_h = 2.0    # глубина потайного отверстия

# Общая высота корпуса с учётом вала
h_reducer = eccentric_h + 5 + 1 + 2.5

# === Выбор подшипника для сепаратора ===
if 2 * Rsep_out < 80:
    bearing_name = "6808-2RS"
    bearing_inner = 40.0
    bearing_outer = 52.0
    bearing_width = 7.0
    flange_extra = 9.5
    cut_z_offset = 11.0
    chamfer_z_offset = 11.5
else:
    bearing_name = "6810-2RS"
    bearing_inner = 50.0
    bearing_outer = 65.0   # добавлено
    bearing_width = 7.0
    flange_extra = 9.5
    cut_z_offset = 11.0
    chamfer_z_offset = 11.5

# Толщина крышки
cap_thickness = bearing_width + 1 + 3  # подшипник + запас + возвышение

# === Вычисляем параметры бокового крепления ===
# Расстояние от центра до боковой поверхности
bracing_offset_y = D / 2 - 6  # 29 при диаметре 70
# Вертикальное смещение опор
bracing_offset_z =  D / 4  # 17.5 при диаметре 70
# Смещение по оси X для опор
bracing_offset_x = 2.25  # 2.25 при диаметре 70 и 90

# === Определение количества отверстий по диаметру ===
if D <= 60:
    n_holes = 4
elif D < 90:
    n_holes = 6
else:
    n_holes = 8

print("\nОсновные параметры ВПТК:")
print(f"- Передаточное число: {i}")
print(f"- Эксцентриситет: {e:.3f} мм")
print(f"- Радиус эксцентрика: {rd:.3f} мм")
print(f"- Внешний радиус впадин: {Rout} мм")
print(f"- Внутренний радиус: {Rin} мм")
print(f"- Число впадин: {zg}")
print(f"- Число роликов: {z_rollers}")
print(f"- Диаметр роликов: {d_roller} мм")
print(f"- Высота роликов: {h_roller} мм")
print(f"- Толщина сепаратора (расчётная): {hc:.3f} мм")
print(f"- Высота сепаратора: {separator_h:.3f} мм")
print(f"- Высота эксцентрика: {eccentric_h:.3f} мм")
print(f"- Высота корпуса редуктора: {h_reducer:.3f} мм")
print(f"- Подшипник на сепараторе: {bearing_name} (Øвнеш = {bearing_outer} мм)")
print(f"- Толщина крышки редуктора: {cap_thickness:.1f} мм")
print(f"- Параметры бокового крепления: смещение Y={bracing_offset_y:.1f} мм, смещение Z={bracing_offset_z:.1f} мм")

# Проверка геометрии
if Rin <= (1.03 * d_roller) / np.sin(np.pi / zg):
    print("Ошибка: Внутренний радиус впадин жесткого колеса Rin({0}мм) должен быть больше: {1}мм. Увеличьте Rout или уменьшите "
          "передаточное число (i)!".format(Rin, (1.03 * d_roller) / np.sin(np.pi / zg)))
    sys.exit(1)

# === Генерация профиля жёсткого колеса ===
theta = np.linspace(0, 2 * np.pi, RESOLUTION, endpoint=False)
S = np.sqrt((r_roller + rd) ** 2 - (e * np.sin(zg * theta)) ** 2)
l = e * np.cos(zg * theta) + S
Xi = np.arctan2(e * zg * np.sin(zg * theta), S)
x_rigid = l * np.sin(theta) + r_roller * np.sin(theta + Xi)
y_rigid = l * np.cos(theta) + r_roller * np.cos(theta + Xi)

# === Минимальная толщина стенки ===
R_out = D / 2
r_rigid = np.sqrt(x_rigid**2 + y_rigid**2)
min_thickness = np.min(R_out - r_rigid)

# === Генерация и поворот основных отверстий ===
angle_step = 2 * np.pi / n_holes
initial_angles = np.linspace(0, 2*np.pi - angle_step, n_holes)
initial_x = [R_out * 0.8 * np.cos(a) for a in initial_angles]
initial_y = [R_out * 0.8 * np.sin(a) for a in initial_angles]

# Поиск наилучшего угла чтобы расположить отверстия в широких местах лепестков
best_angle = 0
min_total_dist = float('inf')
for deg in range(0, 360, 1):
    angle_rad = np.deg2rad(deg)
    rotated_x = []
    rotated_y = []
    for i in range(n_holes):
        x = initial_x[i]
        y = initial_y[i]
        x_rot = x * np.cos(angle_rad) - y * np.sin(angle_rad)
        y_rot = x * np.sin(angle_rad) + y * np.cos(angle_rad)
        rotated_x.append(x_rot)
        rotated_y.append(y_rot)

    total_dist = 0
    r_rigid_orig = np.sqrt(x_rigid**2 + y_rigid**2)
    valleys_orig = []
    for j in range(1, len(r_rigid_orig)-1):
        if r_rigid_orig[j] < r_rigid_orig[j-1] and r_rigid_orig[j] < r_rigid_orig[j+1]:
            valleys_orig.append(j)
    valley_coords = np.array([(x_rigid[i], y_rigid[i]) for i in valleys_orig])

    for i in range(n_holes):
        point = np.array([rotated_x[i], rotated_y[i]])
        if len(valley_coords) > 0:
            dists = np.linalg.norm(valley_coords - point, axis=1)
            total_dist += np.min(dists)
        else:
            total_dist += 1e6

    if total_dist < min_total_dist:
        min_total_dist = total_dist
        best_angle = angle_rad
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

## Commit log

2025-10-20 fix sep
    [vptc_roller_12_8_34_90.scad, vptc_roller_12_8_34_90.stl]
2025-10-26 add ecc shaft
2025-10-27 add motor cover
2025-11-19 its work
    [vptc_roller_12_8_34_90.scad, vptc_roller_19_4_5_70.scad, vptc_roller_19_4_5_70.stl]
2025-11-28 **Title:** Добавлено подробное описание генерируемых деталей в README.md
    - Updated `README.md`: Добавлен раздел "Генерируемые детали" с описанием 11 основных компонентов, включая функции и ключевые характеристики каждой детали
    - Updated `README.md`: Добавлены детализированные сведения о подшипниках, винтах и крепёжных элементах, используемых в сборке
    - Updated `README.md`: Улучшена структура документации с акценто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
2025-12-07 leg kinematics
    [rod_kinematics.scad]
2026-10-11 encoder: encoder_scad variants, KiCad encoder_can board, docs and docker deps
2026-10-11 calc-vpts: CLI/eps refactor, merge manual vptc_roller_19_4_5_70 edits into generator
    - port shoulder h2=12, hip/shin/foot geometry, body() assembly walls, leg_left_front STL union
    - parameterize connect_rod_l=184 and STL import basename by generator params
    - keep eps overshoots, encoder variants, reducer_connector skirt/holes API
    - add regression tests (encoder sizing, manifest, file protection)
2026-10-17 Add printable curved H-section robot foot and fitted connector
2026-10-18 Add 200 mm robot gaits and animated README gallery
2026-10-18 Document 29 CAD parts with renders and parameter guides
2026-10-18 Clarify names of reducer parts adapted for encoder installation
2026-10-18 Fit compact V2 encoder in reducer and add split magnet carriers
2026-10-18 Add powered 2.54 mm SWD clip interface to V2 encoder
    Use five J2 pads for +5V input, GND, SWDIO, SWCLK and NRST. Keep Hall positions and the PCB outline unchanged, document J1/J2 and clip wiring, and include the current KiCad manufacturing and review p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
    Validation: native and portable ERC/DRC and schematic parity passed; 13 generator tests passed; three enclosure intersection probes are empty.
2026-10-21 Fit universal V2 encoder into knee joint
2026-10-26 Save CAN encoder V2.4 for D70 reducer geometry
    Preserve the narrow four-layer 0.8 mm PCB with fixed Hall positions, 0.5 mm via-to-pad clearance and vias outside component bodies. Record the D70 reducer dimensions and variant identifier explicitly.
    Include matching manufacturing files, assembly data, release audits and the mechanical generator integration. Validate with 23 generator tests and zero native ERC, DRC, unconnected and schematic parity errors after unpacking the portable project. Keep ZIP and STL deliverables outside Git.
2026-10-26 Show assembled D70 encoder PCB in project README
2026-10-26 Separate motor cover adapter holes from motor mounting bores
    Place adapter fasteners at 45-degree diagonals independently of the outer cover mounting phase, and use matching coordinates on both mating parts. Update saved SCAD models, catalog images and README 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
    Verify actual bores and solid webs in generated D70/D80 models and the README reference model. All 24 generator tests pass.
